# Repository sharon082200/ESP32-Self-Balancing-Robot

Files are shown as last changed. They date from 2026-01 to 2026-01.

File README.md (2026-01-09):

# 🤖 ESP32 Self-Balancing Robot

A two-wheeled inverted pendulum robot based on **ESP32**, utilizing **PID control** and **Sensor Fusion** for real-time stability.
Designed and built as a personal engineering project.

Robot Demo

## ⚡ Key Features
* **Real-time Control:** Implements a PID algorithm running at ~200Hz loop time.
* **Sensor Fusion:** Uses a **Complementary Filter** to fuse data from the Accelerometer and Gyroscope (MPU6050).
* **Safety Mechanisms:** Auto-shutoff when falling (>35° tilt) and battery voltage monitoring.
* **Custom Hardware Design:** Designed schematic and component libraries using **OrCAD Capture CIS**.

## 🛠️ Hardware Specifications
| Component | Description |
| :--- | :--- |
| **Microcontroller** | ESP32 DevKit V1 (Dual Core, 240MHz) |
| **IMU Sensor** | MPU6050 (6-DOF Gyro + Accel) |
| **Motor Driver** | L298N Dual H-Bridge |
| **Motors** | 12V DC Gear Motors with Encoders |
| **Power** | 2x 18650 Li-Ion Batteries (7.4V - 8.4V) |

## 🔌 Circuit Diagram
Here is the complete wiring schematic for the robot:

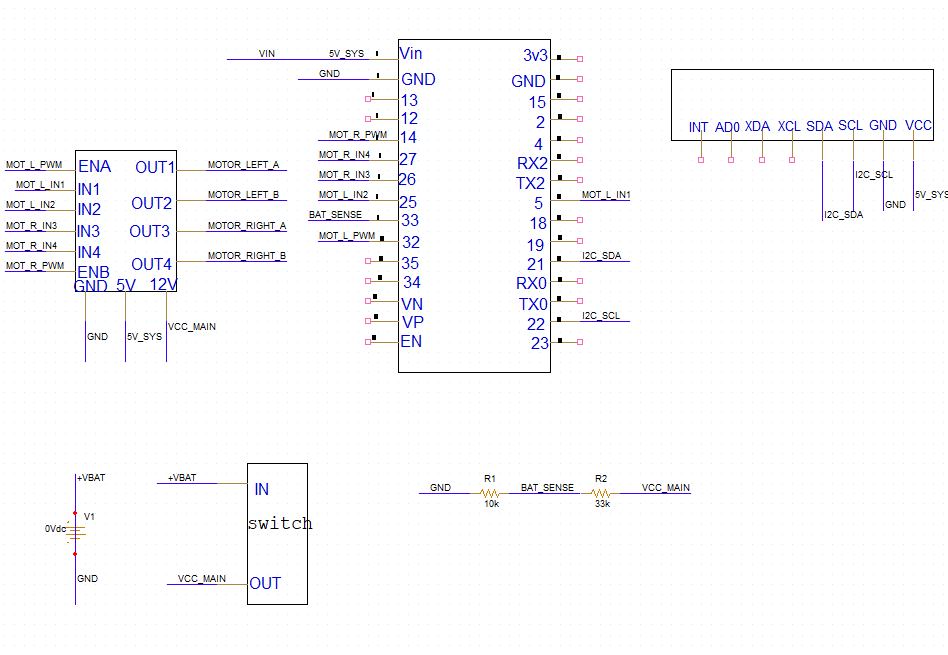
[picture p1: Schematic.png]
Schematic


## 🔋 Battery Monitoring
Designed a voltage divider to monitor the battery via ESP32 ADC:
* **Divider:** 33kΩ (Top) / 10kΩ (Bottom).
* **Logic:** LED indication and Buzzer warnings when voltage drops below 5.6V.

## 🚀 Technical Challenges
**Issue:** "Integral Windup" caused instability when recovering from a tilt.
**Solution:** Tuned the PID controller by clamping the Integral (Ki) term and implementing a conditional integration zone (only integrating when error is small).

## ⚙️ Mechanical Design
The robot's chassis was designed from scratch to ensure structural stability and modularity.
* **Design Software:** FreeCAD (`.FCStd` source files included).
* **Manufacturing:** 3D printed using **PETG** on a **Prusa i3 MK3**.
* **Files:** All STL files are available in the `3D_models` folder for replication.
---
*Created by sharon yerukhimovich - Electrical Engineering Student*

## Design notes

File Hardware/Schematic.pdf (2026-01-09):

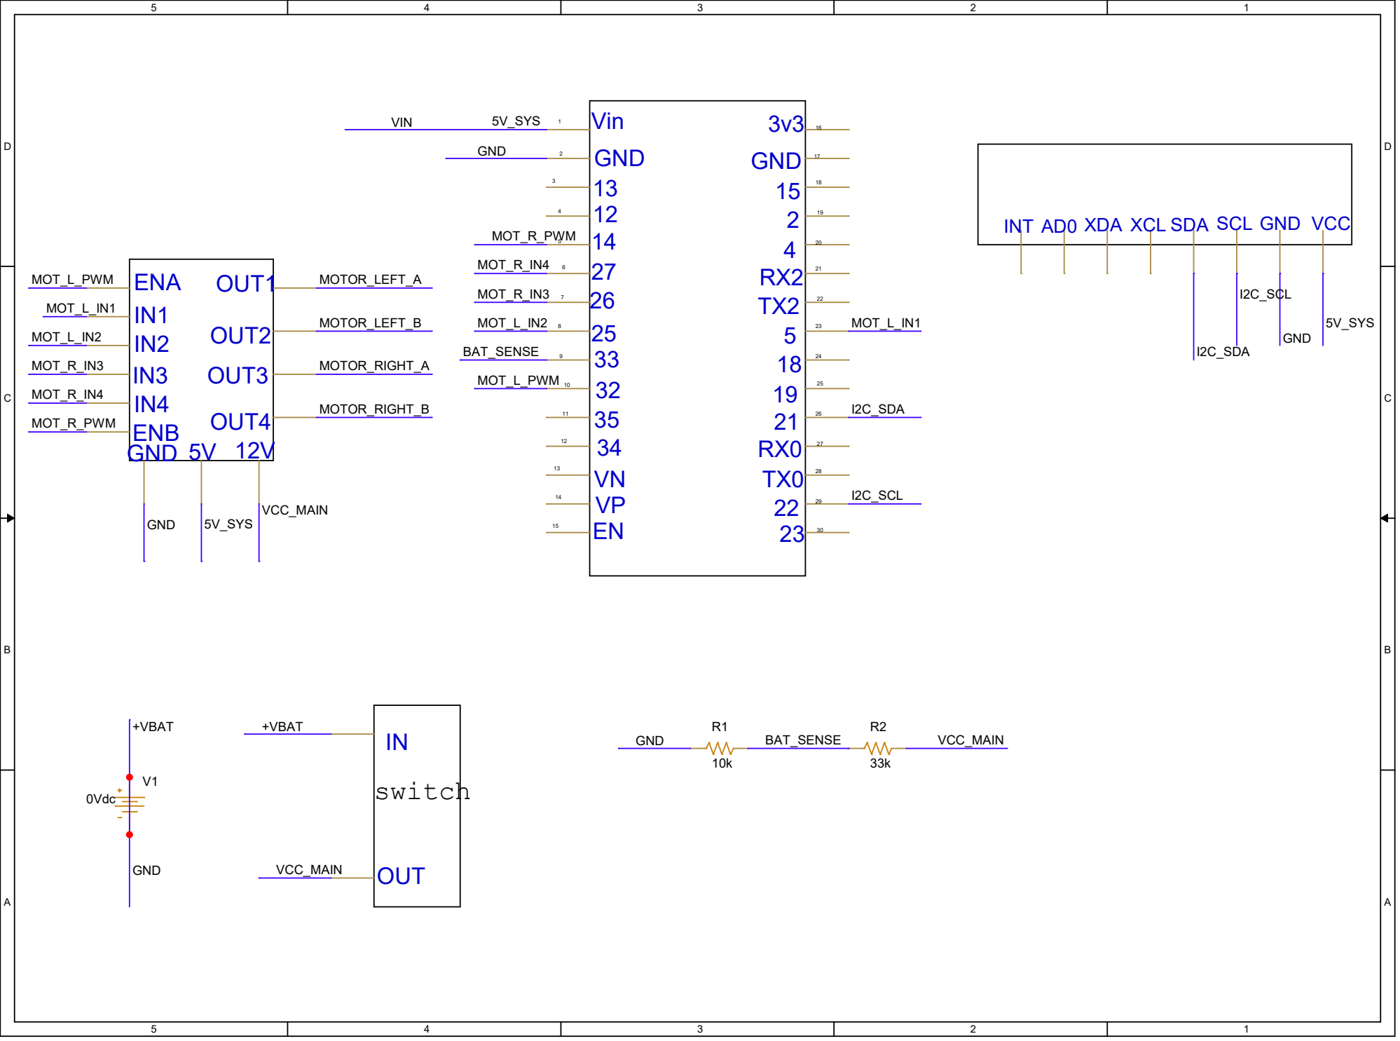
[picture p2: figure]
switch V1; 0Vdc; GND 5V 12V; ENA IN1 IN2 IN3 IN4 ENB; OUT1; OUT2; OUT3; OUT4; INT AD0 XDA XCL SDA SCL GND VCC; 1 Vin GND ² 13 ³ 12 ⁴ 14 ⁵ 27 ⁶ 26 ⁷ 25 ⁸ 33 ⁹ 32 ¹⁰ 35 ¹¹ 34 ¹² VN ¹³ VP ¹⁴ EN ¹⁵; 3v3 16 GND 17 15 18 2; OUT; +VBAT; GND; VCC_MAIN; VIN; 5V_SYS; MOT_L_PWM; MOT_L_IN1; MOT_L_IN2; MOT_R_IN3; MOT_R_IN4; MOT_R_PWM; MOTOR_RIGHT_B; MOTOR_RIGHT_A; MOTOR_LEFT_B; MOTOR_LEFT_A; I2C_SCL; I2C_SDA; BAT_SENSE

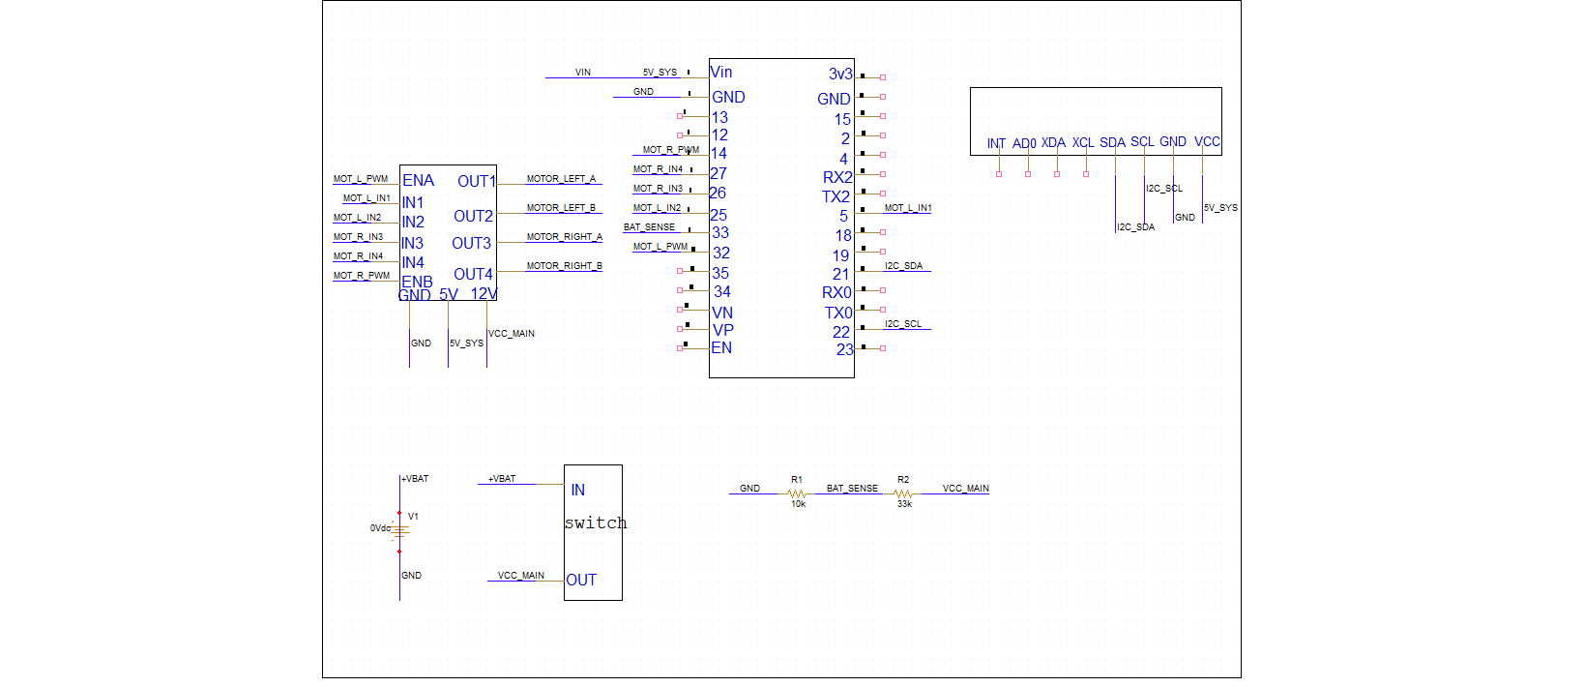
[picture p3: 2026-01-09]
Hardware/SELF_BALANCE.png

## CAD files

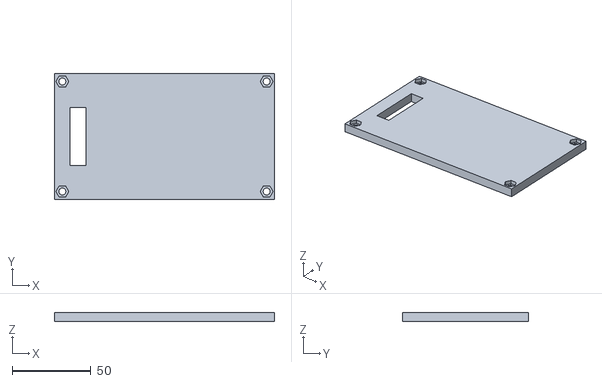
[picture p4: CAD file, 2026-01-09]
3D_models/ROBOT-brain.stl
140.0 x 80.0 x 6.00

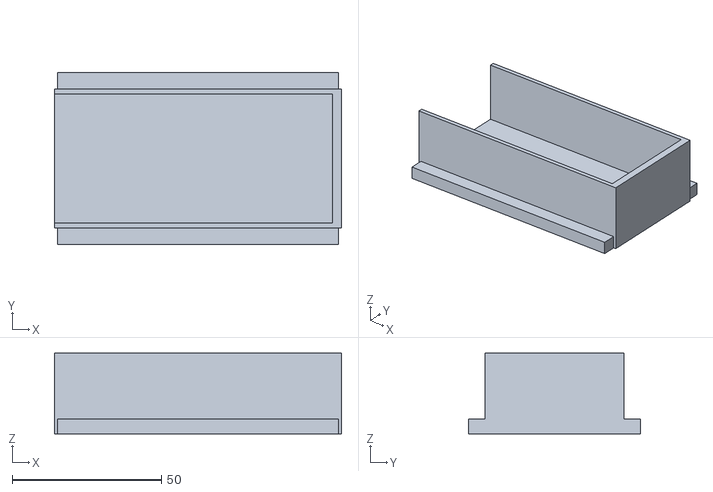
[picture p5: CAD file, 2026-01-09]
3D_models/ROBOT-battery hold.stl
96.0 x 57.6 x 27.0

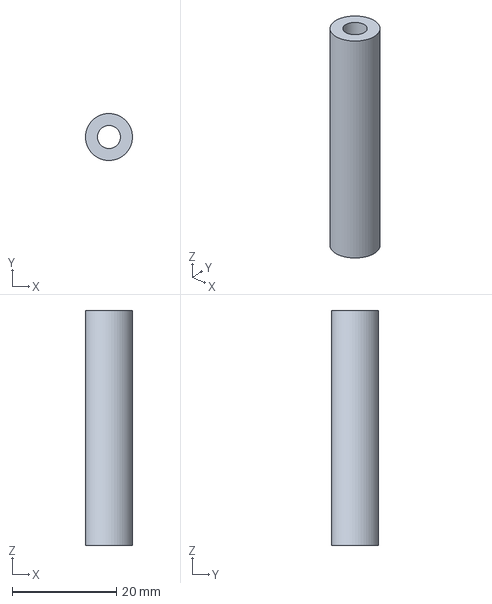
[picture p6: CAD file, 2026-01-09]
3D_models/ROBOT.FCStd
8.99 x 9.00 x 45.0 mm

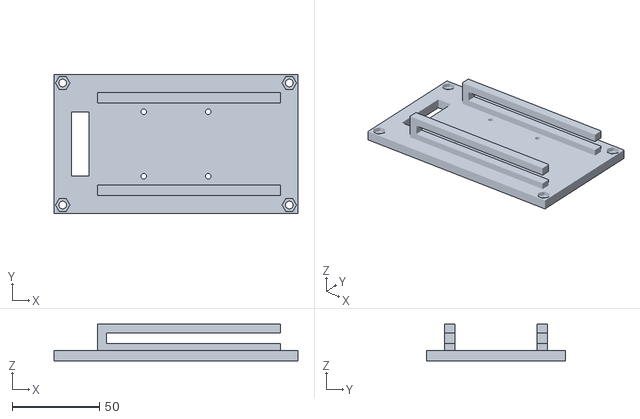
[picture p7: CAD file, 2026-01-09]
3D_models/ROBOT-battery plat.stl
140.0 x 80.0 x 21.0

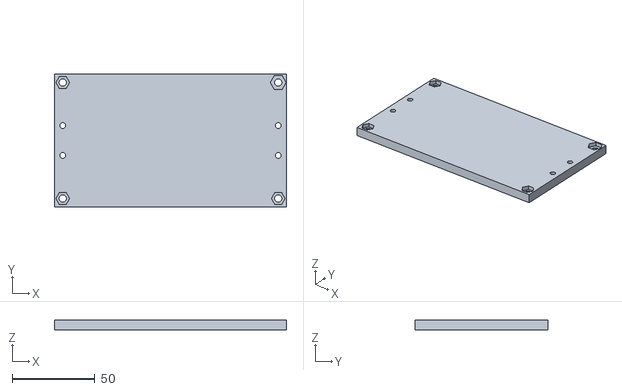
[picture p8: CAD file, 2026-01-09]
3D_models/ROBOT-wheels.stl
140.0 x 80.0 x 6.00

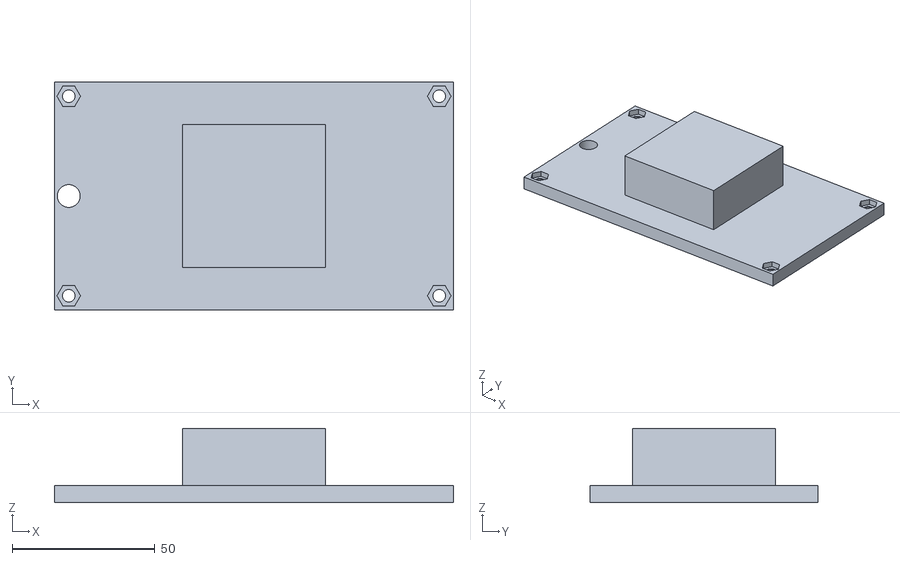
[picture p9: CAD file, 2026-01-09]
3D_models/ROBOT-HEAD.stl
140.0 x 80.0 x 26.0

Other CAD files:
3D_models/ROBOT-Legs 45.stl

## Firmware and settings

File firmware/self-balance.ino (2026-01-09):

/*
 * Project: ESP32 Self-Balancing Robot
 * Author: SHARON YERUKHIMOVICH
 * Description: Two-wheeled inverted pendulum robot using PID control and Sensor Fusion (MPU6050).
 * Features Bluetooth control and battery monitoring.
 */

#include <Wire.h>
#include "BluetoothSerial.h"

BluetoothSerial SerialBT;

// --- Pin Definitions ---
const int ENA = 32;
const int IN1 = 5;
const int IN2 = 25;
const int IN3 = 26;
const int IN4 = 27;
const int ENB = 14;
const int PIN_BATTERY = 35; // Changed name for clarity

const int ENC_L_A = 4;
const int ENC_L_B = 13;
const int ENC_R_A = 18;
const int ENC_R_B = 19;

const int LED_PIN = 2;
const int PIN_BUZZER = 15;

// --- PID Constants ---
float k1 = 41.0f;  // Kp - Proportional
float k2 = 2.5f;   // Kd - Derivative
const float kI = 1.2f; // Ki - Integral

float kx = 0.0f;   // Position P
float kv = 0.01f;  // Position D

// --- State Variables ---
float target_angle = 3.7f; // Mechanical balance point offset
float angle_pitch = 0.0f;
float gyro_rate = 0.0f;
float gyro_bias = 0.0f;
float error_i = 0.0f;

volatile long countLeft = 0;
volatile long countRight = 0;

// --- Control Variables ---
float manual_move_offset = 0.0f;
float manual_turn_offset = 0.0f;
float speed_move_val = 2.5f;
float speed_turn_val = 50.0f;

// --- Function Prototypes ---
void calibrateGyro();
void setMotor(int pwmR, int pwmL);
void IRAM_ATTR readLeft();
void IRAM_ATTR readRight();
void beep(int duration_ms);
bool readSensor(float dt);
void checkBluetooth();
void sendTelemetry();

// Helper: Clamp float values
static inline float clampf(float x, float a, float b) {
  if (x < a) return a;
  if (x > b) return b;
  return x;
}

void setup() {
  Serial.begin(115200);

  // Initialize Bluetooth
  if (!SerialBT.begin("BalancingRobot")) {
    Serial.println("Bluetooth Init Failed!");
    while (1); // Halt execution
  } else {
    Serial.println("Bluetooth Started Successfully!");
  }

  // Initialize I2C
  Wire.begin();
  Wire.setClock(400000);

  // Pin Modes
  pinMode(ENA, OUTPUT);
  pinMode(IN1, OUTPUT);
  pinMode(IN2, OUTPUT);
  pinMode(IN3, OUTPUT);
  pinMode(IN4, OUTPUT);
  pinMode(ENB, OUTPUT);

  pinMode(PIN_BATTERY, INPUT);

  pinMode(ENC_L_A, INPUT_PULLUP);
  pinMode(ENC_L_B, INPUT_PULLUP);
  pinMode(ENC_R_A, INPUT_PULLUP);
  pinMode(ENC_R_B, INPUT_PULLUP);

  // Encoder Interrupts
  attachInterrupt(digitalPinToInterrupt(ENC_L_A), readLeft, RISING);
  attachInterrupt(digitalPinToInterrupt(ENC_R_A), readRight, RISING);

  pinMode(LED_PIN, OUTPUT);
  pinMode(PIN_BUZZER, OUTPUT);

  // Startup sequence
  digitalWrite(LED_PIN, HIGH);
  beep(100);
  digitalWrite(LED_PIN, LOW);

  // Wake up MPU6050
  Wire.beginTransmission(0x68);
  Wire.write(0x6B);
  Wire.write(0);
  Wire.endTransmission(true);

  calibrateGyro();

  // Reset encoders before starting loop
  noInterrupts();
  countLeft = 0;
  countRight = 0;
  interrupts();
}

void loop() {
  const uint32_t loop_time_us = 5000; // 5ms loop = 200Hz
  static uint32_t last_time = 0;

  uint32_t now = micros();

  if (last_time == 0) {
    last_time = now;
    return;
  }

  if (now - last_time < loop_time_us) return;

  float dt = (now - last_time) * 1e-6f;
  last_time = now;

  dt = clampf(dt, 0.001f, 0.01f);

  // Read IMU
  if (!readSensor(dt)) return;

  // Handle Inputs & Telemetry
  checkBluetooth();
  
  static int telemetry_counter = 0;
  if (telemetry_counter++ > 40) { // Send every ~200ms
    sendTelemetry();
    telemetry_counter = 0;
  }

  // Encoder Processing
  long L, R;
  noInterrupts();
  L = countLeft;
  R = countRight;
  interrupts();

  float position = 0.5f * (L + R);
  static float prev_position = 0.0f;
  float speed_raw = (position - prev_position) / dt;
  prev_position = position;

  // Filter speed
  speed_raw = clampf(speed_raw, -3000.0f, 3000.0f);
  static float speed_f = 0.0f;
  const float alpha = 0.4f;
  speed_f = (1.0f - alpha) * speed_f + alpha * speed_raw;
  float speed = speed_f;

  // --- PID Calculation ---
  float position_correction = (kx * position) + (kv * speed);
  position_correction = clampf(position_correction, -6.0f, 6.0f);

  float target_angle_dynamic = target_angle + position_correction + manual_move_offset;
  float error = angle_pitch - target_angle_dynamic;

  // Integral term (Anti-windup logic)
  if (fabs(angle_pitch) < 25.0f && fabs(error) < 6.0f) {
    error_i += error * dt;
  }
  error_i = clampf(error_i, -100.0f, 100.0f);
  float I_term = kI * error_i;
  I_term = clampf(I_term, -60.0f, 60.0f);

  // Gyro filtering
  static float gyro_f = 0.0f;
  const float g_alpha = 0.35f;
  gyro_f = (1.0f - g_alpha) * gyro_f + g_alpha * gyro_rate;

  // Final Output Calculation
  float motorV = ((k1 * error) + (k2 * gyro_f) + I_term);

  // Safety Cutoff (Fall detection)
  if (fabs(angle_pitch) > 35.0f) { // Increased slightly to prevent false trips
    setMotor(0, 0);
    noInterrupts();
    countLeft = 0;
    countRight = 0;
    interrupts();
    prev_position = 0.0f;
    error_i = 0.0f;
    return;
  }

  int pwm = constrain((int)motorV, -250, 250);
  int pwmL = pwm + manual_turn_offset;
  int pwmR = pwm - manual_turn_offset;

  pwmL = constrain(pwmL, -255, 250);
  pwmR = constrain(pwmR, -255, 250);

  setMotor(pwmL, pwmR);

  // LED Status
  if (fabs(error) < 5.0f) digitalWrite(LED_PIN, HIGH);
  else digitalWrite(LED_PIN, LOW);

  // Battery Monitoring
  float sens_v = analogRead(PIN_BATTERY);
  float current_v = sens_v / 4095.0f * 3.3f * 4.3f;

  if (current_v < 5.6f && current_v > 3.0f) { // Added > 3.0f to ignore USB power
    unsigned long m = millis();
    digitalWrite(LED_PIN, HIGH);
    // Beep pattern
    if ((m % 1000) < 100) {
      tone(PIN_BUZZER, 2000);
      digitalWrite(LED_PIN, LOW);
    }
    else if ((m % 1000) > 200 && (m % 1000) < 300) {
      tone(PIN_BUZZER, 2000);
      digitalWrite(LED_PIN, HIGH);
    }
    else {
      noTone(PIN_BUZZER);
      digitalWrite(LED_PIN, LOW);
    }
  }
}

void setMotor(int pwmL, int pwmR) {
  const int offset = 29; // Min PWM to overcome friction
  const int dead_zone = 6;

  if (abs(pwmL) > dead_zone) {
    int s = (pwmL > 0) ? 1 : -1;
    pwmL = s * (abs(pwmL) + offset);
  }

  if (abs(pwmR) > dead_zone) {
    int s = (pwmR > 0) ? 1 : -1;
    pwmR = s * (abs(pwmR) + offset);
  }

  // Left Motor Logic
  if (pwmL >= 0) {
    digitalWrite(IN1, LOW);
    digitalWrite(IN2, HIGH);
  } else {
    digitalWrite(IN2, LOW);
    digitalWrite(IN1, HIGH);
    pwmL = -pwmL;
  }

  // Right Motor Logic
  if (pwmR >= 0) {
    digitalWrite(IN4, LOW);
    digitalWrite(IN3, HIGH);
  } else {
    digitalWrite(IN3, LOW);
    digitalWrite(IN4, HIGH);
    pwmR = -pwmR;
  }

  // Final Safety Clamp
  if (pwmL > 255) pwmL = 255;
  if (pwmR > 255) pwmR = 255;

  analogWrite(ENA, pwmL);
  analogWrite(ENB, pwmR);
}

bool readSensor(float dt) {
  Wire.beginTransmission(0x68);
  Wire.write(0x3B);
  if (Wire.endTransmission(false) != 0) return false;

  int n = Wire.requestFrom(0x68, 14, true);
  if (n != 14 || Wire.available() < 14) return false;

  int16_t Acx = Wire.read() << 8 | Wire.read();
  int16_t Acy = Wire.read() << 8 | Wire.read();
  int16_t Acz = Wire.read() << 8 | Wire.read();

  Wire.read(); // Temperature high
  Wire.read(); // Temperature low

  int16_t GyroX = Wire.read() << 8 | Wire.read();
  int16_t GyroY = Wire.read() << 8 | Wire.read();
  int16_t GyroZ = Wire.read() << 8 | Wire.read();

  float angle = atan2((float)Acx, (float)Acz) * 180.0f / PI;
  gyro_rate = -((float)GyroY) / 131.0f - gyro_bias;

  // Complementary Filter
  angle_pitch = 0.98f * (angle_pitch + gyro_rate * dt) + 0.02f * angle;

  return true;
}

void calibrateGyro() {
  long sum = 0;
  const int N = 1200;
  int valid = 0;
  for (int i = 0; i < N; i++) {
    Wire.beginTransmission(0x68);
    Wire.write(0x45); // GyroY High
    if (Wire.endTransmission(false) != 0) continue;

    int n = Wire.requestFrom(0x68, 2, true);
    if (n != 2 || Wire.available() < 2) continue;

    int16_t Gy = Wire.read() << 8 | Wire.read();
    sum += Gy;
    valid++;
    delay(2);
  }
  if (valid < 200) gyro_bias = 0.0f;
  else gyro_bias = (sum / (float)valid) / 131.0f;
  
  beep(100);
}

void beep(int duration_ms) {
  unsigned long end = millis() + duration_ms;
  while (millis() < end) {
    digitalWrite(PIN_BUZZER, HIGH);
    delayMicroseconds(250);
    digitalWrite(PIN_BUZZER, LOW);
    delayMicroseconds(250);
  }
}

void IRAM_ATTR readLeft() {
  if (digitalRead(ENC_L_B) > 0) {
    countLeft--;
  } else {
    countLeft++;
  }
}

void IRAM_ATTR readRight() {
  if (digitalRead(ENC_R_B) > 0) {
    countRight++;
  } else {
    countRight--;
  }
}

void checkBluetooth() {
  if (SerialBT.available()) {
    char cmd = SerialBT.read();
    
    // Speed Modes
    if (cmd == '1') {
      speed_move_val = 1.5f;
      speed_turn_val = 30.0f;
    } else if (cmd == '2') {
      speed_move_val = 2.5f;
      speed_turn_val = 50.0f;
    } else if (cmd == '3') {
      speed_move_val = 4.0f;
      speed_turn_val = 70.0f;
    }

    // Direction Control
    if (cmd == 'F') { manual_move_offset = -speed_move_val; }      // Forward
    else if (cmd == 'B') { manual_move_offset = speed_move_val; }  // Backward
    else if (cmd == 'L') { manual_turn_offset = speed_turn_val; }  // Left
    else if (cmd == 'R') { manual_turn_offset = -speed_turn_val; } // Right
    else if (cmd == 'S') { // Stop
      manual_move_offset = 0.0f;
      manual_turn_offset = 0.0f;
    }
  }
}

void sendTelemetry() {
  float sens_v = analogRead(PIN_BATTERY);
  float current_v = sens_v / 4095.0f * 3.3f * 4.3f;

  if (SerialBT.hasClient()) {
    SerialBT.print("Bat: ");
    SerialBT.print(current_v);
    SerialBT.print("V | Angle: ");
    SerialBT.println(angle_pitch);
  }
}
